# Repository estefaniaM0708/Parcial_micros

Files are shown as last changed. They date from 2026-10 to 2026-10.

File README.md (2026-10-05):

# 🪙 Sistema de Logística de Monedas Inteligentes — Grupo 5

**Segundo parcial · Microcontroladores · Universidad Militar Nueva Granada**

> **Elemento diferencial del grupo (5):** *Selector en cadena de vasos de moneda por visión computacional → control por ESP32 → aparcamiento por voz.*

---

## Contenido

1. [Resumen](#1-resumen)
2. [Alcance y decisiones de diseño](#2-alcance-y-decisiones-de-diseño)
3. [Arquitectura del sistema](#3-arquitectura-del-sistema)
4. [Requerimientos funcionales y no funcionales](#4-requerimientos-funcionales-y-no-funcionales)
5. [Diagramas de bloques por módulo](#5-diagramas-de-bloques-por-módulo)
6. [Selección y justificación de materiales](#6-selección-y-justificación-de-materiales)
7. [Diseño mecánico y CAD del carro](#7-diseño-mecánico-y-cad-del-carro)
8. [Diseño electrónico: pines y esquemas](#8-diseño-electrónico-pines-y-esquemas)
9. [Identificación visual de monedas](#9-identificación-visual-de-monedas)
10. [Firmware de las ESP32-S3](#10-firmware-de-las-esp32-s3)
11. [Aplicación Streamlit: dashboard y control por voz](#11-aplicación-streamlit-dashboard-y-control-por-voz)
12. [Simulación en PyBullet](#12-simulación-en-pybullet)
13. [Paso a paso para ejecutar](#13-paso-a-paso-para-ejecutar)
14. [Resultados de las pruebas](#14-resultados-de-las-pruebas)
15. [Qué hace falta (trabajo pendiente)](#15-qué-hace-falta-trabajo-pendiente)
16. [Estructura del repositorio](#16-estructura-del-repositorio)
17. [Evidencias](#17-evidencias)

---

## 1. Resumen

Se diseñó, simuló e implementó en firmware la parte del *Sistema de Logística de Monedas Inteligentes* que corresponde al grupo 5:

| Etapa | Qué hace | Dónde |
|---|---|---|
| **Identificación de monedas** | Una **cinta transportadora** lleva cada moneda bajo una cámara; un programa de **visión por computador** (OpenCV) la identifica por **diámetro y color** (dorado/plateado, centro y anillo). | `1_vision/` |
| **Selector en cadena de vasos** | Una **cadena con 6 vasos** (uno por denominación + rechazo) gira para poner bajo la caída el vaso correcto; la moneda cae en él. | `2_estacion_esp32/` |
| **Carro con ESP32-S3** | Carro diferencial que recibe el vaso lleno, sigue la pista y **esquiva tres obstáculos** hasta la meta. | `3_carro_esp32/`, `6_cad/` |
| **Aparcamiento por voz** | La orden hablada (*«estaciona el carro»*) se convierte en texto y el carro retrocede solo hasta la estación usando su **ultrasonido trasero**. | `4_app_streamlit/` |
| **Dashboard en tiempo real** | Streamlit muestra **cantidad, valor y peso** de las monedas, el estado de los vasos y del carro, comunicándose **por Wi-Fi** con las ESP32-S3. | `4_app_streamlit/` |
| **Simulación** | Todo el flujo funciona en **PyBullet**, usando el **mismo código de visión** que la cámara real. | `5_simulacion/` |

---

## 2. Alcance y decisiones de diseño

La arquitectura general del parcial tiene cinco bloques: **contador de monedas → transporte y embalaje → carro → pista con obstáculos → dashboard y chatbot**. Sobre esa base, el grupo tomó estas decisiones:

1. **Identificación por cinta transportadora y visión (en lugar del contador por ranuras).** Las monedas entran una a una a una banda negra. Una compuerta las detiene bajo la cámara, el PC las identifica y la ESP32 decide a qué vaso van. Esto permite saber la **denominación exacta**, y con ella el **valor** y el **peso** de cada moneda, que son las variables que pide el dashboard.
2. **Selector en cadena de vasos (elemento diferencial 5).** En lugar de un actuador por denominación, una sola caída alimenta una **cadena cerrada con 6 vasos**. La cadena gira por el camino más corto hasta dejar el vaso correcto bajo la caída. Con un solo motor paso a paso se clasifican las 5 denominaciones más el rechazo.
3. **Control por ESP32 y aparcamiento por voz.** El carro no se conduce con un joystick. Recibe **órdenes habladas** desde la app (*estacionar, cargar, meta, alto, adelante…*). El aparcamiento es **automático**: en reversa, con el HC-SR04 trasero y un pitido de sensor de parqueo, se detiene a 6 cm de la estación.
4. **Comunicación inalámbrica por Wi-Fi (HTTP).** Cada ESP32-S3 tiene un pequeño servidor web (`/estado`, `/moneda`, `/entregar`, `/cmd`). La app de Streamlit y el programa de visión le hablan por HTTP. Si no hay red, cada placa crea su propio punto de acceso.
5. **Simulación primero.** Todo se validó en PyBullet a **escala 4:1**. La cámara virtual genera imágenes que se clasifican con `vision_monedas.py`, el mismo archivo que se usa con la cámara real.

---

## 3. Arquitectura del sistema

```mermaid
flowchart LR
    subgraph EST["🏭 Estación (ESP32-S3 #1)"]
        T[Tolva] --> B[Banda transportadora<br/>28BYJ-48 + ULN2003]
        B --> C{Compuerta<br/>servo SG90}
        C -->|moneda detenida<br/>sensor IR| CAM[(Cámara USB)]
        C -->|liberada| CAD[Caída]
        CAD --> CH[Cadena de 6 vasos<br/>NEMA 17 + A4988]
        CH --> EMP[Empujador servo<br/>+ celda de carga HX711]
    end
    subgraph PC["💻 Computador"]
        CAM --> VIS["vision_monedas.py<br/>OpenCV: diámetro + color"]
        APP[App Streamlit<br/>dashboard + voz]
    end
    subgraph CAR["🚗 Carro (ESP32-S3 #2)"]
        MOT[2 motores TT<br/>TB6612FNG]
        US[HC-SR04 frontal y trasero]
        IR[3 sensores de línea TCRT5000]
    end
    VIS -- "HTTP /moneda?valor=500" --> EST
    APP -- "HTTP /estado · /entregar" --> EST
    APP -- "HTTP /cmd?c=estacionar" --> CAR
    EMP -- "vaso lleno" --> CAR
    CAR --> P[Pista con 3 obstáculos] --> M[🏁 Meta]
```

### Secuencia de operación

```mermaid
sequenceDiagram
    participant U as Usuario (voz)
    participant A as App Streamlit
    participant V as Visión (PC)
    participant E as ESP32 Estación
    participant C as ESP32 Carro
    E->>E: Banda avanza hasta que el IR detecta una moneda (compuerta cerrada)
    V->>V: Captura → segmenta → mide Ø y color → $500
    V->>E: GET /moneda?valor=500
    E->>E: Cadena gira al vaso de $500, abre compuerta, la moneda cae
    A->>E: GET /estado (cada 1 s) → dashboard
    U->>A: «estaciona el carro»
    A->>C: GET /cmd?c=estacionar
    C->>C: Reversa con ultrasonido trasero hasta 6 cm (pitidos)
    U->>A: «carga el vaso de quinientos»
    A->>E: GET /entregar?valor=500
    E->>E: Cadena lleva el vaso al puesto de entrega, lo pesa y lo empuja al carro
    U->>A: «ve a la meta»
    A->>C: GET /cmd?c=meta
    C->>C: Sigue la línea, esquiva 3 obstáculos, se detiene en la franja de meta
```

---

## 4. Requerimientos funcionales y no funcionales

### Funcionales

| ID | Requerimiento | Cómo se cumple |
|---|---|---|
| RF-01 | Identificar las monedas colombianas de $50, $100, $200, $500 y $1000 | Visión por diámetro (±0,6 mm) y color de centro y anillo |
| RF-02 | Separar cada moneda en el vaso de su denominación | Cadena de vasos indexada por motor paso a paso |
| RF-03 | Enviar a un vaso de rechazo las monedas no reconocidas | Puesto "rechazo" y *timeout* de 5 s sin respuesta de visión |
| RF-04 | Calcular cantidad, valor y peso de las monedas procesadas | Tabla de pesos oficiales + celda de carga en la entrega |
| RF-05 | Entregar un vaso lleno al carro | Empujador en el puesto de entrega + porta-vaso en el carro |
| RF-06 | Estacionar el carro en la zona de carga por orden de voz | Reconocimiento de voz en la app + reversa con HC-SR04 |
| RF-07 | Llevar el vaso a la meta esquivando 3 obstáculos | Seguidor de línea + ultrasonido frontal + maniobra de esquive |
| RF-08 | Mostrar las métricas en tiempo real | Dashboard Streamlit que consulta `/estado` cada 1 s |
| RF-09 | Comunicación inalámbrica PC ↔ ESP32 | Wi-Fi + HTTP (STA o punto de acceso propio) |

### No funcionales

| ID | Requerimiento | Valor objetivo |
|---|---|---|
| RNF-01 | Exactitud de clasificación | ≥ 95 % con iluminación controlada |
| RNF-02 | Tiempo por moneda | ≤ 8 s (inspección + indexado + caída) |
| RNF-03 | Latencia de las órdenes de voz | ≤ 2 s desde que se termina de hablar |
| RNF-04 | Precisión de aparcamiento | ± 1 cm de la distancia objetivo (6 cm) |
| RNF-05 | Autonomía del carro | ≥ 30 min con 2 × 18650 |
| RNF-06 | Seguridad | Parada ante obstáculo < 18 cm; comandos manuales temporizados |
| RNF-07 | Mantenibilidad | Pines, velocidades y umbrales agrupados como constantes al inicio de cada archivo |
| RNF-08 | Reproducibilidad | Toda la lógica probada en simulación antes del montaje |

---

## 5. Diagramas de bloques por módulo

### Estación (banda + selector en cadena)

```mermaid
flowchart TB
    F12[Fuente 12 V 3 A] --> A4988[Driver A4988] --> N17[NEMA 17: cadena de vasos]
    F12 --> BUCK1[LM2596 → 5 V] --> ULN[ULN2003] --> M28[28BYJ-48: banda]
    BUCK1 --> SV1[Servo compuerta]
    BUCK1 --> SV2[Servo empujador]
    BUCK1 --> ESP1[ESP32-S3 #1]
    IRM[Sensor IR FC-51<br/>moneda en inspección] --> ESP1
    HOME[TCRT5000<br/>home de la cadena] --> ESP1
    CELDA[Celda de carga 1 kg] --> HX[HX711] --> ESP1
    ESP1 --> A4988
    ESP1 --> ULN
    ESP1 --> SV1
    ESP1 --> SV2
    ESP1 <-. Wi-Fi .-> PC[("PC: visión + app")]
```

### Visión por computador

```mermaid
flowchart LR
    CAM[Cámara USB cenital<br/>+ anillo LED] --> HSV[BGR → HSV]
    HSV --> UMB["Umbral de brillo V &gt; 80<br/>banda negra"]
    UMB --> MOR[Apertura + cierre]
    MOR --> CON[Contornos<br/>área y circularidad]
    CON --> DIA[Diámetro equivalente<br/>px → mm]
    CON --> COL[Color del centro y del anillo<br/>H y S en HSV]
    DIA --> CLA[Costo mínimo<br/>vs tabla de monedas]
    COL --> CLA
    CLA --> HTTP[HTTP a la estación]
```

### Carro

```mermaid
flowchart TB
    BAT[2 × 18650 · 7,4 V] --> SW[Interruptor] --> TB[TB6612FNG]
    SW --> BUCK[MP1584 → 5 V] --> ESP2[ESP32-S3 #2]
    BUCK --> USF[HC-SR04 frontal]
    BUCK --> UST[HC-SR04 trasero]
    TB --> MI[Motor TT izquierdo]
    TB --> MD[Motor TT derecho]
    LIN[3 × TCRT5000] --> ESP2
    USF --> ESP2
    UST --> ESP2
    ESP2 --> TB
    ESP2 --> BZ[Buzzer de parqueo]
    ESP2 <-. Wi-Fi .-> APP[(App Streamlit)]
```

---

## 6. Selección y justificación de materiales

| Componente | Cant. | Selección | Justificación |
|---|---|---|---|
| Microcontrolador | 2 | **ESP32-S3 DevKitC-1** | Wi-Fi integrado para el dashboard, doble núcleo, MicroPython, muchos GPIO y ADC; el curso ya lo usa |
| Banda transportadora | 1 | 28BYJ-48 + ULN2003, banda de caucho/EVA **negra** de 40 mm | Velocidad baja y constante (~19 mm/s), barato; el negro da contraste a la visión |
| Cadena de vasos | 1 | **NEMA 17 + A4988** (1/8 de micropaso), piñón Ø40 mm, cadena/correa cerrada | Par y velocidad suficientes para mover 6 vasos con monedas (~1 s por puesto); posicionamiento en lazo abierto preciso |
| Compuerta y empujador | 2 | Servo **SG90 / MG90S** | Movimiento angular simple, control directo por PWM |
| Detección de moneda | 1 | Sensor IR **FC-51** | Detecta la moneda bajo la cámara para detener la banda |
| Referencia de la cadena | 1 | **TCRT5000** | *Homing* del puesto 0 al encender |
| Peso | 1 | Celda de carga 1 kg + **HX711** | Mide el peso real del vaso antes de entregarlo (variable "peso" del dashboard) |
| Cámara | 1 | Webcam USB 1080p + anillo LED | Resolución de ~10 px/mm a 12 cm; luz uniforme para medir el color |
| Motores del carro | 2 | **Motorreductor TT 1:48** + rueda 65 mm | Estándar, económico y con el par suficiente para 0,9 kg |
| Driver del carro | 1 | **TB6612FNG** | Lógica de 3,3 V y mayor eficiencia que el L298N (menor caída de tensión) |
| Distancia | 2 | **HC-SR04** (frontal y trasero) | El trasero hace el aparcamiento; el frontal detecta los obstáculos (ECHO con divisor a 3,3 V) |
| Línea | 3 | **TCRT5000** | Seguir la línea de la pista y detectar la franja de meta |
| Energía del carro | 1 | 2 × 18650 + **MP1584** 5 V | 7,4 V para los motores y 5 V regulados para la lógica |
| Estructura del carro | — | PLA impreso / acrílico 4 mm | Piezas del CAD de este repositorio; fáciles de fabricar |
| Vasos | 6 | Vasos de Ø70 mm | Encajan en el porta-vaso de Ø78 mm del carro |

---

## 7. Diseño mecánico y CAD del carro

El CAD está en `6_cad/` y se genera desde **una sola fuente de cotas** (`generar_cad.py`):

| Archivo | Uso |
|---|---|
| `carro.scad` | Modelo **paramétrico** para OpenSCAD (gratuito). Con la variable `pieza` se exporta cada parte imprimible: `chasis`, `piso2`, `portavaso`, `soporte_sensor` (F6 → F7 = STL) |
| `carro_ensamble.stl` | Ensamble 3D completo en mm (se abre en cualquier visor o *slicer*) |
| `carro.urdf` | Modelo para PyBullet (escala 4:1, la de la simulación) |
| `plano_carro.png` | Plano con vistas superior y lateral acotadas |

| Isométrica | Trasera (porta-vaso) |
|---|---|
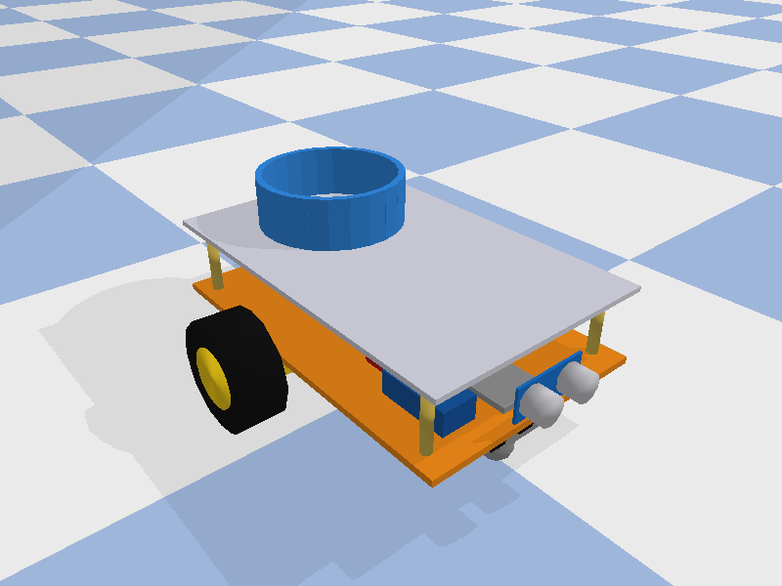
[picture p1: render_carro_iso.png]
CAD isométrico
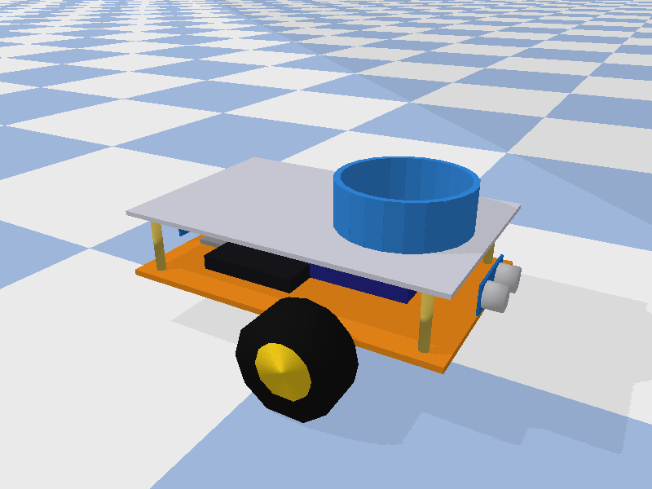
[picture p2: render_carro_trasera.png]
CAD trasera
|  |  |

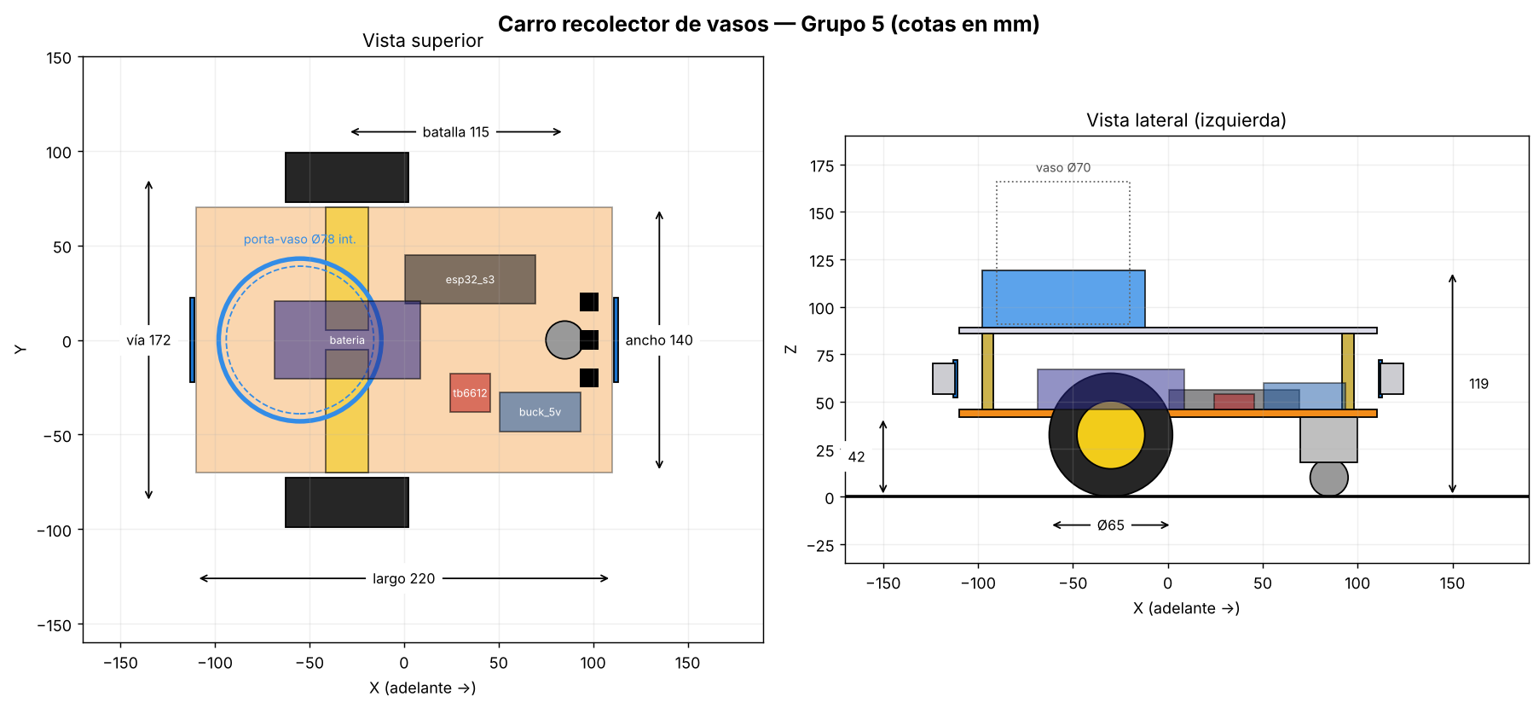
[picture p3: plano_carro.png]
Plano acotado


### Cotas principales

| Parámetro | Valor |
|---|---|
| Chasis (largo × ancho) | 220 × 140 mm, dos pisos (4 mm + 3 mm) con separadores de 40 mm |
| Ruedas motrices | Ø65 mm, vía 172 mm, eje a 30 mm detrás del centro |
| Rueda loca | Bola de Ø20 mm, a 85 mm delante del centro (batalla 115 mm) |
| Porta-vaso | Ø78 mm interior × 30 mm de alto, sobre el piso superior (atrás) |
| Altura total | 119 mm (sin vaso) |
| Sensores | HC-SR04 adelante y atrás; 3 × TCRT5000 bajo la parte delantera |

**Por qué el porta-vaso va atrás:** el carro se **estaciona en reversa**, así que el porta-vaso queda pegado al empujador de la estación, y el sensor trasero mide justo esa distancia.

### Estación

| Elemento | Dimensiones reales |
|---|---|
| Banda | 400 × 40 mm, superficie negra, rodillos Ø25 mm con rodamientos 608 |
| Cámara | A 105 mm sobre la banda, en la zona de inspección (a 75 mm del final) |
| Cadena de vasos | Óvalo de 1170 mm (6 puestos cada 195 mm), piñones Ø40 mm |
| Puestos | Caída en el puesto 0; entrega en el puesto 3 (lado opuesto) |

<details>
<summary><b>Código: <code>6_cad/generar_cad.py</code></b> (genera SCAD, STL, URDF y plano)</summary>

```python
"""
generar_cad.py  -  CAD del carro recolector de vasos (Grupo 5)

Una sola fuente de verdad para el diseño mecánico del carro. A partir de las
cotas reales (en mm) este script genera:

  carro.scad           modelo paramétrico para OpenSCAD (editable; F6 + F7 exporta STL)
  carro_ensamble.stl   ensamble 3D en mm (para ver en cualquier visor/slicer)
  carro.urdf           modelo para PyBullet (escala configurable)
  plano_carro.png      plano con vistas superior y lateral acotadas

Uso:  python generar_cad.py            (escala del URDF = 4, la de la simulación)
      python generar_cad.py --escala 1 (URDF a tamaño real)
"""

import argparse
import math
import os
import struct

AQUI = os.path.dirname(os.path.abspath(__file__))

# ---------------------------------------------------------------------------
# COTAS DEL CARRO (mm). Ejes: X adelante, Y izquierda, Z arriba. Origen: centro
# del chasis inferior a nivel del piso.
# ---------------------------------------------------------------------------
L, W = 220.0, 140.0            # chasis inferior (acrilico / PLA 4 mm)
T_CHASIS = 4.0
Z_CHASIS = 42.0                # cara inferior del chasis
R_RUEDA, A_RUEDA = 32.5, 26.0  # rueda TT de 65 mm
X_EJE = -30.0                  # eje de las ruedas motrices
Y_RUEDA = W / 2 + 3 + A_RUEDA / 2
MOTOR = (65.0, 22.5, 18.8)     # motorreductor TT (largo en Y)
X_LOCA, R_BOLA = 85.0, 10.0    # rueda loca (ball caster)
H_SEPARADOR, R_SEPARADOR = 40.0, 3.0
T_PISO2 = 3.0                  # chasis superior
Z_PISO2 = Z_CHASIS + T_CHASIS + H_SEPARADOR
X_VASO = -55.0                 # porta-vaso sobre el piso superior
R_EXT_VASO, R_INT_VASO, H_PORTAVASO = 43.0, 39.0, 30.0

# Componentes (centro x, centro y, tamaño x, tamaño y, tamaño z, z inferior, color)
Z_SUP = Z_CHASIS + T_CHASIS
COMPONENTES = {
    "esp32_s3":  (35.0, 32.0, 69.0, 26.0, 10.0, Z_SUP, (0.10, 0.10, 0.12)),
    "tb6612":    (35.0, -28.0, 21.0, 20.0, 8.0, Z_SUP, (0.75, 0.10, 0.10)),
    "bateria":   (-30.0, 0.0, 77.0, 41.0, 21.0, Z_SUP, (0.15, 0.15, 0.55)),
    "buck_5v":   (72.0, -38.0, 43.0, 21.0, 14.0, Z_SUP, (0.10, 0.35, 0.65)),
}
HCSR04 = [(+1, L / 2 + 2.0), (-1, -L / 2 - 2.0)]   # (sentido, x de la placa)
Z_HCSR04 = Z_SUP + 16.0
IR_LINEA = [(L / 2 - 12.0, y) for y in (-20.0, 0.0, 20.0)]

COLORES = {
    "chasis": (0.95, 0.55, 0.10), "piso2": (0.85, 0.85, 0.90), "rueda": (0.08, 0.08, 0.08),
    "rin": (0.95, 0.80, 0.10), "motor": (0.95, 0.80, 0.10), "loca": (0.6, 0.6, 0.6),
    "separador": (0.80, 0.70, 0.30), "portavaso": (0.20, 0.55, 0.90), "sensor": (0.10, 0.45, 0.80),
    "transductor": (0.80, 0.80, 0.82), "ir": (0.05, 0.05, 0.05),
}

# ---------------------------------------------------------------------------
# Lista de piezas como primitivas (sirve para STL, URDF y plano)
# ---------------------------------------------------------------------------
def piezas():
    """Devuelve (nombre, tipo, parametros, color). Tipos: caja / cilindro / esfera.
    caja: (cx, cy, cz, sx, sy, sz); cilindro: (cx, cy, cz, r, h, eje); esfera: (cx, cy, cz, r)"""
    p = []
    p.append(("chasis", "caja", (0, 0, Z_CHASIS + T_CHASIS / 2, L, W, T_CHASIS), COLORES["chasis"]))
    p.append(("piso2", "caja", (0, 0, Z_PISO2 + T_PISO2 / 2, L, W, T_PISO2), COLORES["piso2"]))
    for sx in (-1, 1):
        for sy in (-1, 1):
            p.append(("separador", "cilindro",
                      (sx * (L / 2 - 15), sy * (W / 2 - 10), Z_SUP + H_SEPARADOR / 2,
                       R_SEPARADOR, H_SEPARADOR, "z"), COLORES["separador"]))
    for s in (-1, 1):
        p.append(("motor", "caja", (X_EJE, s * (5 + MOTOR[0] / 2), Z_CHASIS - MOTOR[2] / 2,
                                    MOTOR[1], MOTOR[0], MOTOR[2]), COLORES["motor"]))
        p.append(("rueda", "cilindro", (X_EJE, s * Y_RUEDA, R_RUEDA, R_RUEDA, A_RUEDA, "y"), COLORES["rueda"]))
        p.append(("rin", "cilindro", (X_EJE, s * (Y_RUEDA + A_RUEDA / 2), R_RUEDA,
                                      R_RUEDA * 0.55, 2.0, "y"), COLORES["rin"]))
    p.append(("soporte_loca", "caja", (X_LOCA, 0, (2 * R_BOLA + Z_CHASIS) / 2 + R_BOLA / 2,
                                       30, 30, Z_CHASIS - 1.5 * R_BOLA), COLORES["loca"]))
    p.append(("bola_loca", "esfera", (X_LOCA, 0, R_BOLA, R_BOLA), COLORES["loca"]))
    for nombre, (cx, cy, sx, sy, sz, z0, color) in COMPONENTES.items():
        p.append((nombre, "caja", (cx, cy, z0 + sz / 2, sx, sy, sz), color))
    for sentido, x in HCSR04:
        p.append(("hcsr04", "caja", (x, 0, Z_HCSR04, 1.6, 45.0, 20.0), COLORES["sensor"]))
        for y in (-13.0, 13.0):
            p.append(("transductor", "cilindro", (x + sentido * 6.8, y, Z_HCSR04, 8.0, 12.0, "x"),
                      COLORES["transductor"]))
    for x, y in IR_LINEA:
        p.append(("ir_linea", "caja", (x, y, Z_CHASIS - 6, 10, 10, 12), COLORES["ir"]))
    # porta-vaso: anillo formado por 24 segmentos (para STL/URDF) / tubo en OpenSCAD
    n = 24
    r_med = (R_EXT_VASO + R_INT_VASO) / 2
    ancho = 2 * math.pi * r_med / n * 1.05
    for i in range(n):
        a = 2 * math.pi * i / n
        p.append(("portavaso", "caja_rot",
                  (X_VASO + r_med * math.cos(a), r_med * math.sin(a), Z_PISO2 + T_PISO2 + H_PORTAVASO / 2,
                   R_EXT_VASO - R_INT_VASO, ancho, H_PORTAVASO, a), COLORES["portavaso"]))
    return p

# ---------------------------------------------------------------------------
# 1) OpenSCAD
# ---------------------------------------------------------------------------
def generar_scad(ruta):
    s = f"""// carro.scad - Carro recolector de vasos (Grupo 5) - cotas en mm
// Generado por generar_cad.py. Abrir en OpenSCAD: F5 vista previa, F6 render, F7 exportar STL.
// Cambia "pieza" para exportar cada parte imprimible por separado.

pieza = "ensamble";   // "ensamble", "chasis", "piso2", "portavaso", "soporte_sensor"
$fn = 64;

L = {L}; W = {W};
t_chasis = {T_CHASIS}; z_chasis = {Z_CHASIS};
r_rueda = {R_RUEDA}; a_rueda = {A_RUEDA};
x_eje = {X_EJE}; y_rueda = {Y_RUEDA};
x_loca = {X_LOCA}; r_bola = {R_BOLA};
h_sep = {H_SEPARADOR}; t_piso2 = {T_PISO2};
z_piso2 = z_chasis + t_chasis + h_sep;
x_vaso = {X_VASO}; r_ext_vaso = {R_EXT_VASO}; r_int_vaso = {R_INT_VASO}; h_portavaso = {H_PORTAVASO};
r_esquina = 10;

module placa_redondeada(l, w, t, r) {{
    hull() for (sx = [-1, 1], sy = [-1, 1])
        translate([sx * (l / 2 - r), sy * (w / 2 - r), 0]) cylinder(r = r, h = t);
}}

// Chasis inferior: agujeros para separadores, rueda loca, motores y paso de cables
module chasis() {{
    difference() {{
        placa_redondeada(L, W, t_chasis, r_esquina);
        for (sx = [-1, 1], sy = [-1, 1])
            translate([sx * (L / 2 - 15), sy * (W / 2 - 10), -1]) cylinder(d = 3.4, h = t_chasis + 2);
        for (dx = [-10, 10], dy = [-10, 10])                 // rueda loca
            translate([x_loca + dx, dy, -1]) cylinder(d = 3.4, h = t_chasis + 2);
        for (s = [-1, 1], dx = [-8, 8])                      // soportes de motor
            translate([x_eje + dx, s * 40, -1]) cylinder(d = 3.4, h = t_chasis + 2);
        translate([0, 0, -1]) linear_extrude(t_chasis + 2)   // paso de cables
            hull() {{ translate([-10, 0]) circle(d = 14); translate([10, 0]) circle(d = 14); }}
        for (y = [-20, 0, 20])                                // sensores IR de linea
            translate([L / 2 - 12, y, -1]) cylinder(d = 3.4, h = t_chasis + 2);
    }}
}}

// Chasis superior con agujero para el porta-vaso y ventilacion
module piso2() {{
    difference() {{
        placa_redondeada(L, W, t_piso2, r_esquina);
        for (sx = [-1, 1], sy = [-1, 1])
            translate([sx * (L / 2 - 15), sy * (W / 2 - 10), -1]) cylinder(d = 3.4, h = t_piso2 + 2);
        for (i = [0 : 3])
            translate([20 + i * 18, -25, -1]) cube([10, 50, t_piso2 + 2]);
    }}
}}

// Porta-vaso: tubo con base, recibe un vaso de 70 mm
module portavaso() {{
    difference() {{
        union() {{
            cylinder(r = r_ext_vaso, h = h_portavaso);
            cylinder(r = r_ext_vaso + 6, h = 2);             // pestaña de apoyo
        }}
        translate([0, 0, 2]) cylinder(r = r_int_vaso, h = h_portavaso);
        translate([0, 0, -1]) cylinder(r = r_int_vaso - 8, h = 4);
        translate([-r_ext_vaso - 1, -8, 12]) cube([10, 16, h_portavaso]);   // ranura sensor
    }}
}}

// Soporte en L para el HC-SR04
module soporte_sensor() {{
    difference() {{
        union() {{
            translate([-2, -25, 0]) cube([2, 50, 26]);
            translate([-14, -25, 0]) cube([14, 50, 2]);
        }}
        for (y = [-13, 13]) translate([-3, y, 16]) rotate([0, 90, 0]) cylinder(d = 16.5, h = 4);
        for (y = [-18, 18]) translate([-7, y, -1]) cylinder(d = 3.4, h = 4);
    }}
}}

module rueda() {{ rotate([90, 0, 0]) cylinder(r = r_rueda, h = a_rueda, center = true); }}
module motor_tt() {{ cube([22.5, 65, 18.8], center = true); }}

module ensamble() {{
    color("orange") translate([0, 0, z_chasis]) chasis();
    color("gainsboro") translate([0, 0, z_piso2]) piso2();
    color("goldenrod") for (sx = [-1, 1], sy = [-1, 1])
        translate([sx * (L / 2 - 15), sy * (W / 2 - 10), z_chasis + t_chasis]) cylinder(r = 3, h = h_sep);
    for (s = [-1, 1]) {{
        color("gold") translate([x_eje, s * (5 + 65 / 2), z_chasis - 18.8 / 2]) motor_tt();
        color("black") translate([x_eje, s * y_rueda, r_rueda]) rueda();
    }}
    color("silver") translate([x_loca, 0, r_bola]) sphere(r = r_bola);
    color("silver") translate([x_loca - 15, -15, 2 * r_bola - 2]) cube([30, 30, z_chasis - 2 * r_bola + 2]);
    color("dodgerblue") translate([x_vaso, 0, z_piso2 + t_piso2]) portavaso();
    color("steelblue") translate([L / 2, 0, z_chasis + t_chasis]) soporte_sensor();
    color("steelblue") translate([-L / 2, 0, z_chasis + t_chasis]) mirror([1, 0, 0]) soporte_sensor();
"""
    for nombre, (cx, cy, sx, sy, sz, z0, color) in COMPONENTES.items():
        s += (f"    color([{color[0]}, {color[1]}, {color[2]}]) "
              f"translate([{cx - sx / 2}, {cy - sy / 2}, {z0}]) cube([{sx}, {sy}, {sz}]);  // {nombre}\n")
    s += """}

if (pieza == "ensamble") ensamble();
if (pieza == "chasis") chasis();
if (pieza == "piso2") piso2();
if (pieza == "portavaso") portavaso();
if (pieza == "soporte_sensor") soporte_sensor();
"""
    with open(ruta, "w", encoding="utf-8") as f:
        f.write(s)

# ---------------------------------------------------------------------------
# 2) STL (ensamble de primitivas)
# ---------------------------------------------------------------------------
def _caja(c, s, ang=0.0):
    cx, cy, cz = c
    hx, hy, hz = s[0] / 2, s[1] / 2, s[2] / 2
    ca, sa = math.cos(ang), math.sin(ang)
    v = []
    for dx, dy, dz in [(-1, -1, -1), (1, -1, -1), (1, 1, -1), (-1, 1, -1),
                       (-1, -1, 1), (1, -1, 1), (1, 1, 1), (-1, 1, 1)]:
        x, y = dx * hx, dy * hy
        v.append((cx + ca * x - sa * y, cy + sa * x + ca * y, cz + dz * hz))
    caras = [(0, 2, 1), (0, 3, 2), (4, 5, 6), (4, 6, 7), (0, 1, 5), (0, 5, 4),
             (1, 2, 6), (1, 6, 5), (2, 3, 7), (2, 7, 6), (3, 0, 4), (3, 4, 7)]
    return [(v[a], v[b], v[c]) for a, b, c in caras]

def _cilindro(c, r, h, eje, n=40):
    def punto(a, t):
        u, w = r * math.cos(a), r * math.sin(a)
        if eje == "z":
            return (c[0] + u, c[1] + w, c[2] + t)
        if eje == "y":
            return (c[0] + u, c[1] + t, c[2] + w)
        return (c[0] + t, c[1] + u, c[2] + w)
    tri = []
    for i in range(n):
        a0, a1 = 2 * math.pi * i / n, 2 * math.pi * (i + 1) / n
        p0, p1 = punto(a0, -h / 2), punto(a1, -h / 2)
        q0, q1 = punto(a0, h / 2), punto(a1, h / 2)
        cb = {"z": (c[0], c[1], c[2] - h / 2), "y": (c[0], c[1] - h / 2, c[2]), "x": (c[0] - h / 2, c[1], c[2])}[eje]
        ct = {"z": (c[0], c[1], c[2] + h / 2), "y": (c[0], c[1] + h / 2, c[2]), "x": (c[0] + h / 2, c[1], c[2])}[eje]
        tri += [(p0, p1, q1), (p0, q1, q0), (cb, p1, p0), (ct, q0, q1)]
    if eje == "y":   # el eje y invierte la orientacion de las caras
        tri = [(a, c_, b) for a, b, c_ in tri]
    return tri

def _esfera(c, r, n=20):
    tri = []
    for i in range(n):
        t0, t1 = math.pi * i / n, math.pi * (i + 1) / n
        for j in range(2 * n):
            f0, f1 = 2 * math.pi * j / (2 * n), 2 * math.pi * (j + 1) / (2 * n)
            def pt(t, f):
                return (c[0] + r * math.sin(t) * math.cos(f), c[1] + r * math.sin(t) * math.sin(f), c[2] + r * math.cos(t))
            a, b, cc, d = pt(t0, f0), pt(t1, f0), pt(t1, f1), pt(t0, f1)
            tri += [(a, b, cc), (a, cc, d)]
    return tri

def triangulos():
    tri = []
    for nombre, tipo, prm, _ in piezas():
        if tipo == "caja":
            tri += _caja(prm[:3], prm[3:6])
        elif tipo == "caja_rot":
            tri += _caja(prm[:3], prm[3:6], prm[6])
        elif tipo == "cilindro":
            tri += _cilindro(prm[:3], prm[3], prm[4], prm[5])
        else:
            tri += _esfera(prm[:3], prm[3])
    return tri

def generar_stl(ruta):
    tri = triangulos()
    with open(ruta, "wb") as f:
        f.write(b"carro recolector grupo 5 (mm)".ljust(80, b" "))
        f.write(struct.pack("<I", len(tri)))
        for a, b, c in tri:
            u = [b[i] - a[i] for i in range(3)]
            v = [c[i] - a[i] for i in range(3)]
            n = (u[1] * v[2] - u[2] * v[1], u[2] * v[0] - u[0] * v[2], u[0] * v[1] - u[1] * v[0])
            m = math.sqrt(sum(x * x for x in n)) or 1.0
            f.write(struct.pack("<12fH", n[0] / m, n[1] / m, n[2] / m, *a, *b, *c, 0))
    return len(tri)

# ---------------------------------------------------------------------------
# 3) URDF para PyBullet
# ---------------------------------------------------------------------------
def generar_urdf(ruta, escala):
    k = escala / 1000.0                     # mm -> m, multiplicado por la escala
    z_base = Z_CHASIS + T_CHASIS / 2        # el marco del chasis esta en su centro

    def f(v):
        return " ".join("%.5f" % x for x in v)

    visuales = []
    for nombre, tipo, prm, color in piezas():
        if nombre in ("rueda", "rin", "bola_loca"):
            continue
        mat = '<material name="m_%s"><color rgba="%.2f %.2f %.2f 1"/></material>' % (nombre, *color)
        if tipo in ("caja", "caja_rot"):
            cx, cy, cz, sx, sy, sz = prm[:6]
            yaw = prm[6] if tipo == "caja_rot" else 0.0
            visuales.append(
                f'    <visual name="{nombre}"><origin xyz="{f((cx * k, cy * k, (cz - z_base) * k))}" rpy="0 0 {yaw:.5f}"/>'
                f'<geometry><box size="{f((sx * k, sy * k, sz * k))}"/></geometry>{mat}</visual>')
        elif tipo == "cilindro":
            cx, cy, cz, r, h, eje = prm
            rpy = {"z": "0 0 0", "y": "1.5708 0 0", "x": "0 1.5708 0"}[eje]
            visuales.append(
                f'    <visual name="{nombre}"><origin xyz="{f((cx * k, cy * k, (cz - z_base) * k))}" rpy="{rpy}"/>'
                f'<geometry><cylinder radius="{r * k:.5f}" length="{h * k:.5f}"/></geometry>{mat}</visual>')

    masa_chasis = 0.9 * escala                     # kg (0,9 kg reales; se escala para la simulacion)
    Lm, Wm, Hm = L * k, W * k, (Z_PISO2 + T_PISO2 - Z_CHASIS) * k
    Ixx = masa_chasis * (Wm ** 2 + Hm ** 2) / 12
    Iyy = masa_chasis * (Lm ** 2 + Hm ** 2) / 12
    Izz = masa_chasis * (Lm ** 2 + Wm ** 2) / 12
    m_rueda = 0.05 * escala
    Ir_eje = m_rueda * (R_RUEDA * k) ** 2 / 2
    Ir_rad = m_rueda * (3 * (R_RUEDA * k) ** 2 + (A_RUEDA * k) ** 2) / 12
    colisiones = (
        f'    <collision><origin xyz="0 0 0"/><geometry><box size="{f((L * k, W * k, T_CHASIS * k))}"/></geometry></collision>\n'
        f'    <collision><origin xyz="0 0 {(Z_PISO2 + T_PISO2 / 2 - z_base) * k:.5f}"/>'
        f'<geometry><box size="{f((L * k, W * k, T_PISO2 * k))}"/></geometry></collision>\n'
        f'    <collision><origin xyz="{f((-30 * k, 0, (Z_SUP + 10 - z_base) * k))}"/>'
        f'<geometry><box size="{f((90 * k, 50 * k, 20 * k))}"/></geometry></collision>')

    rueda = lambda lado, s: f"""
  <link name="rueda_{lado}">
    <visual><origin rpy="1.5708 0 0"/><geometry><cylinder radius="{R_RUEDA * k:.5f}" length="{A_RUEDA * k:.5f}"/></geometry>
      <material name="m_rueda"><color rgba="0.08 0.08 0.08 1"/></material></visual>
    <visual><origin xyz="0 {s * A_RUEDA / 2 * k:.5f} 0" rpy="1.5708 0 0"/><geometry><cylinder radius="{R_RUEDA * 0.55 * k:.5f}" length="{2 * k:.5f}"/></geometry>
      <material name="m_rin"><color rgba="0.95 0.8 0.1 1"/></material></visual>
    <collision><origin rpy="1.5708 0 0"/><geometry><cylinder radius="{R_RUEDA * k:.5f}" length="{A_RUEDA * k:.5f}"/></geometry></collision>
    <inertial><mass value="{m_rueda:.3f}"/><inertia ixx="{Ir_rad:.6f}" iyy="{Ir_eje:.6f}" izz="{Ir_rad:.6f}" ixy="0" ixz="0" iyz="0"/></inertial>
  </link>
  <joint name="motor_{lado}" type="continuous">
    <parent link="chasis"/><child link="rueda_{lado}"/>
    <origin xyz="{f((X_EJE * k, s * Y_RUEDA * k, (R_RUEDA - z_base) * k))}"/><axis xyz="0 1 0"/>
  </joint>"""

    urdf = f"""<?xml version="1.0"?>
<!-- carro.urdf - Carro recolector de vasos (Grupo 5). Generado por generar_cad.py, escala {escala}:1 -->
<robot name="carro_recolector">
  <link name="chasis">
{chr(10).join(visuales)}
{colisiones}
    <inertial><origin xyz="{-15 * k:.5f} 0 0"/><mass value="{masa_chasis:.3f}"/>
      <inertia ixx="{Ixx:.6f}" iyy="{Iyy:.6f}" izz="{Izz:.6f}" ixy="0" ixz="0" iyz="0"/></inertial>
  </link>
{rueda("izq", 1)}
{rueda("der", -1)}
  <link name="rueda_loca">
    <visual><geometry><sphere radius="{R_BOLA * k:.5f}"/></geometry>
      <material name="m_loca"><color rgba="0.6 0.6 0.6 1"/></material></visual>
    <collision><geometry><sphere radius="{R_BOLA * k:.5f}"/></geometry></collision>
    <inertial><mass value="{0.01 * escala:.3f}"/><inertia ixx="{Ir_rad / 5:.6f}" iyy="{Ir_rad / 5:.6f}" izz="{Ir_rad / 5:.6f}" ixy="0" ixz="0" iyz="0"/></inertial>
  </link>
  <joint name="loca" type="fixed">
    <parent link="chasis"/><child link="rueda_loca"/>
    <origin xyz="{f((X_LOCA * k, 0, (R_BOLA - z_base) * k))}"/>
  </joint>
  <link name="porta_vaso"><inertial><mass value="0.001"/><inertia ixx="1e-6" iyy="1e-6" izz="1e-6" ixy="0" ixz="0" iyz="0"/></inertial></link>
  <joint name="porta_vaso" type="fixed">
    <parent link="chasis"/><child link="porta_vaso"/>
    <origin xyz="{f((X_VASO * k, 0, (Z_PISO2 + T_PISO2 - z_base) * k))}"/>
  </joint>
  <link name="sensor_frontal"><inertial><mass value="0.001"/><inertia ixx="1e-6" iyy="1e-6" izz="1e-6" ixy="0" ixz="0" iyz="0"/></inertial></link>
  <joint name="sensor_frontal" type="fixed">
    <parent link="chasis"/><child link="sensor_frontal"/>
    <origin xyz="{f(((L / 2 + 14) * k, 0, (Z_HCSR04 - z_base) * k))}"/>
  </joint>
  <link name="sensor_trasero"><inertial><mass value="0.001"/><inertia ixx="1e-6" iyy="1e-6" izz="1e-6" ixy="0" ixz="0" iyz="0"/></inertial></link>
  <joint name="sensor_trasero" type="fixed">
    <parent link="chasis"/><child link="sensor_trasero"/>
    <origin xyz="{f((-(L / 2 + 14) * k, 0, (Z_HCSR04 - z_base) * k))}" rpy="0 0 3.14159"/>
  </joint>
</robot>
"""
    with open(ruta, "w", encoding="utf-8") as fh:
        fh.write(urdf)

# ---------------------------------------------------------------------------
# 4) Plano acotado
# ---------------------------------------------------------------------------
def generar_plano(ruta):
    import matplotlib
    matplotlib.use("Agg")
    import matplotlib.pyplot as plt
    from matplotlib.patches import Rectangle, Circle

    fig, (a1, a2) = plt.subplots(1, 2, figsize=(14, 6.2))
    fig.suptitle("Carro recolector de vasos — Grupo 5 (cotas en mm)", fontsize=14, weight="bold")

    def cota(ax, p0, p1, texto, off=(0, 0)):
        ax.annotate("", p0, p1, arrowprops=dict(arrowstyle="<->", lw=1))
        ax.text((p0[0] + p1[0]) / 2 + off[0], (p0[1] + p1[1]) / 2 + off[1], texto,
                ha="center", va="center", fontsize=9, backgroundcolor="white")

    # --- vista superior ---
    a1.set_title("Vista superior")
    a1.add_patch(Rectangle((-L / 2, -W / 2), L, W, fc=COLORES["chasis"], ec="k", alpha=0.35))
    for s in (-1, 1):
        a1.add_patch(Rectangle((X_EJE - R_RUEDA, s * Y_RUEDA - A_RUEDA / 2), 2 * R_RUEDA, A_RUEDA, fc="0.15", ec="k"))
        a1.add_patch(Rectangle((X_EJE - MOTOR[1] / 2, s * (5 + MOTOR[0] / 2) - MOTOR[0] / 2),
                               MOTOR[1], MOTOR[0], fc=COLORES["motor"], ec="k", alpha=0.6))
    a1.add_patch(Circle((X_LOCA, 0), R_BOLA, fc="0.6", ec="k"))
    a1.add_patch(Circle((X_VASO, 0), R_EXT_VASO, fc="none", ec=COLORES["portavaso"], lw=3))
    a1.add_patch(Circle((X_VASO, 0), R_INT_VASO, fc="none", ec=COLORES["portavaso"], lw=1, ls="--"))
    for nombre, (cx, cy, sx, sy, sz, z0, color) in COMPONENTES.items():
        a1.add_patch(Rectangle((cx - sx / 2, cy - sy / 2), sx, sy, fc=color, ec="k", alpha=0.55))
        a1.text(cx, cy, nombre, ha="center", va="center", fontsize=7, color="w")
    for _, x in HCSR04:
        a1.add_patch(Rectangle((x - 1, -22.5), 2, 45, fc=COLORES["sensor"], ec="k"))
    for x, y in IR_LINEA:
        a1.add_patch(Rectangle((x - 5, y - 5), 10, 10, fc="k"))
    cota(a1, (-L / 2, -Y_RUEDA - 40), (L / 2, -Y_RUEDA - 40), f"largo {L:.0f}")
    cota(a1, (L / 2 + 25, -W / 2), (L / 2 + 25, W / 2), f"ancho {W:.0f}", off=(0, 0))
    cota(a1, (-L / 2 - 25, Y_RUEDA), (-L / 2 - 25, -Y_RUEDA), f"vía {2 * Y_RUEDA:.0f}", off=(0, 0))
    cota(a1, (X_EJE, W / 2 + 40), (X_LOCA, W / 2 + 40), f"batalla {X_LOCA - X_EJE:.0f}")
    a1.text(X_VASO, R_EXT_VASO + 8, f"porta-vaso Ø{2 * R_INT_VASO:.0f} int.", ha="center", fontsize=8,
            color=COLORES["portavaso"])
    a1.set_xlim(-170, 190); a1.set_ylim(-160, 150); a1.set_aspect("equal"); a1.grid(alpha=0.2)
    a1.set_xlabel("X (adelante →)"); a1.set_ylabel("Y")

    # --- vista lateral ---
    a2.set_title("Vista lateral (izquierda)")
    a2.add_patch(Rectangle((-L / 2, Z_CHASIS), L, T_CHASIS, fc=COLORES["chasis"], ec="k"))
    a2.add_patch(Rectangle((-L / 2, Z_PISO2), L, T_PISO2, fc=COLORES["piso2"], ec="k"))
    for sx in (-1, 1):
        a2.add_patch(Rectangle((sx * (L / 2 - 15) - 3, Z_SUP), 6, H_SEPARADOR, fc=COLORES["separador"], ec="k"))
    a2.add_patch(Circle((X_EJE, R_RUEDA), R_RUEDA, fc="0.15", ec="k"))
    a2.add_patch(Circle((X_EJE, R_RUEDA), R_RUEDA * 0.55, fc=COLORES["rin"], ec="k"))
    a2.add_patch(Circle((X_LOCA, R_BOLA), R_BOLA, fc="0.6", ec="k"))
    a2.add_patch(Rectangle((X_LOCA - 15, 2 * R_BOLA - 2), 30, Z_CHASIS - 2 * R_BOLA + 2, fc="0.75", ec="k"))
    a2.add_patch(Rectangle((X_VASO - R_EXT_VASO, Z_PISO2 + T_PISO2), 2 * R_EXT_VASO, H_PORTAVASO,
                           fc=COLORES["portavaso"], ec="k", alpha=0.8))
    a2.add_patch(Rectangle((X_VASO - 35, Z_PISO2 + T_PISO2 + 2), 70, 75, fc="none", ec="0.4", ls=":"))
    a2.text(X_VASO, Z_PISO2 + 85, "vaso Ø70", ha="center", fontsize=8, color="0.3")
    for nombre, (cx, cy, sx, sy, sz, z0, color) in COMPONENTES.items():
        a2.add_patch(Rectangle((cx - sx / 2, z0), sx, sz, fc=color, ec="k", alpha=0.5))
    for s, x in HCSR04:
        a2.add_patch(Rectangle((x - 1, Z_HCSR04 - 10), 2, 20, fc=COLORES["sensor"], ec="k"))
        a2.add_patch(Rectangle((x + (0 if s > 0 else -12), Z_HCSR04 - 8), 12, 16, fc=COLORES["transductor"], ec="k"))
    a2.plot([-170, 190], [0, 0], "k-", lw=2)
    altura = Z_PISO2 + T_PISO2 + H_PORTAVASO
    cota(a2, (150, 0), (150, altura), f"{altura:.0f}", off=(14, 0))
    cota(a2, (-150, 0), (-150, Z_CHASIS), f"{Z_CHASIS:.0f}", off=(-14, 0))
    cota(a2, (X_EJE - R_RUEDA, -15), (X_EJE + R_RUEDA, -15), f"Ø{2 * R_RUEDA:.0f}")
    a2.set_xlim(-170, 190); a2.set_ylim(-35, 190); a2.set_aspect("equal"); a2.grid(alpha=0.2)
    a2.set_xlabel("X (adelante →)"); a2.set_ylabel("Z")
    plt.tight_layout()
    plt.savefig(ruta, dpi=130, bbox_inches="tight")
    plt.close(fig)

if __name__ == "__main__":
    ap = argparse.ArgumentParser()
    ap.add_argument("--escala", type=float, default=4.0, help="escala del URDF (la simulación usa 4)")
    args = ap.parse_args()
    generar_scad(os.path.join(AQUI, "carro.scad"))
    n = generar_stl(os.path.join(AQUI, "carro_ensamble.stl"))
    generar_urdf(os.path.join(AQUI, "carro.urdf"), args.escala)
    generar_plano(os.path.join(AQUI, "plano_carro.png"))
    print("carro.scad, carro_ensamble.stl (%d triangulos), carro.urdf (escala %g) y plano_carro.png generados"
          % (n, args.escala))
```

</details>

<details>
<summary><b>Código: <code>6_cad/carro.scad</code></b> (CAD paramétrico de OpenSCAD)</summary>

```openscad
// carro.scad - Carro recolector de vasos (Grupo 5) - cotas en mm
// Generado por generar_cad.py. Abrir en OpenSCAD: F5 vista previa, F6 render, F7 exportar STL.
// Cambia "pieza" para exportar cada parte imprimible por separado.

pieza = "ensamble";   // "ensamble", "chasis", "piso2", "portavaso", "soporte_sensor"
$fn = 64;

L = 220.0; W = 140.0;
t_chasis = 4.0; z_chasis = 42.0;
r_rueda = 32.5; a_rueda = 26.0;
x_eje = -30.0; y_rueda = 86.0;
x_loca = 85.0; r_bola = 10.0;
h_sep = 40.0; t_piso2 = 3.0;
z_piso2 = z_chasis + t_chasis + h_sep;
x_vaso = -55.0; r_ext_vaso = 43.0; r_int_vaso = 39.0; h_portavaso = 30.0;
r_esquina = 10;

module placa_redondeada(l, w, t, r) {
    hull() for (sx = [-1, 1], sy = [-1, 1])
        translate([sx * (l / 2 - r), sy * (w / 2 - r), 0]) cylinder(r = r, h = t);
}

// Chasis inferior: agujeros para separadores, rueda loca, motores y paso de cables
module chasis() {
    difference() {
        placa_redondeada(L, W, t_chasis, r_esquina);
        for (sx = [-1, 1], sy = [-1, 1])
            translate([sx * (L / 2 - 15), sy * (W / 2 - 10), -1]) cylinder(d = 3.4, h = t_chasis + 2);
        for (dx = [-10, 10], dy = [-10, 10])                 // rueda loca
            translate([x_loca + dx, dy, -1]) cylinder(d = 3.4, h = t_chasis + 2);
        for (s = [-1, 1], dx = [-8, 8])                      // soportes de motor
            translate([x_eje + dx, s * 40, -1]) cylinder(d = 3.4, h = t_chasis + 2);
        translate([0, 0, -1]) linear_extrude(t_chasis + 2)   // paso de cables
            hull() { translate([-10, 0]) circle(d = 14); translate([10, 0]) circle(d = 14); }
        for (y = [-20, 0, 20])                                // sensores IR de linea
            translate([L / 2 - 12, y, -1]) cylinder(d = 3.4, h = t_chasis + 2);
    }
}

// Chasis superior con agujero para el porta-vaso y ventilacion
module piso2() {
    difference() {
        placa_redondeada(L, W, t_piso2, r_esquina);
        for (sx = [-1, 1], sy = [-1, 1])
            translate([sx * (L / 2 - 15), sy * (W / 2 - 10), -1]) cylinder(d = 3.4, h = t_piso2 + 2);
        for (i = [0 : 3])
            translate([20 + i * 18, -25, -1]) cube([10, 50, t_piso2 + 2]);
    }
}

// Porta-vaso: tubo con base, recibe un vaso de 70 mm
module portavaso() {
    difference() {
        union() {
            cylinder(r = r_ext_vaso, h = h_portavaso);
            cylinder(r = r_ext_vaso + 6, h = 2);             // pestaña de apoyo
        }
        translate([0, 0, 2]) cylinder(r = r_int_vaso, h = h_portavaso);
        translate([0, 0, -1]) cylinder(r = r_int_vaso - 8, h = 4);
        translate([-r_ext_vaso - 1, -8, 12]) cube([10, 16, h_portavaso]);   // ranura sensor
    }
}

// Soporte en L para el HC-SR04
module soporte_sensor() {
    difference() {
        union() {
            translate([-2, -25, 0]) cube([2, 50, 26]);
            translate([-14, -25, 0]) cube([14, 50, 2]);
        }
        for (y = [-13, 13]) translate([-3, y, 16]) rotate([0, 90, 0]) cylinder(d = 16.5, h = 4);
        for (y = [-18, 18]) translate([-7, y, -1]) cylinder(d = 3.4, h = 4);
    }
}

module rueda() { rotate([90, 0, 0]) cylinder(r = r_rueda, h = a_rueda, center = true); }
module motor_tt() { cube([22.5, 65, 18.8], center = true); }

module ensamble() {
    color("orange") translate([0, 0, z_chasis]) chasis();
    color("gainsboro") translate([0, 0, z_piso2]) piso2();
    color("goldenrod") for (sx = [-1, 1], sy = [-1, 1])
        translate([sx * (L / 2 - 15), sy * (W / 2 - 10), z_chasis + t_chasis]) cylinder(r = 3, h = h_sep);
    for (s = [-1, 1]) {
        color("gold") translate([x_eje, s * (5 + 65 / 2), z_chasis - 18.8 / 2]) motor_tt();
        color("black") translate([x_eje, s * y_rueda, r_rueda]) rueda();
    }
    color("silver") translate([x_loca, 0, r_bola]) sphere(r = r_bola);
    color("silver") translate([x_loca - 15, -15, 2 * r_bola - 2]) cube([30, 30, z_chasis - 2 * r_bola + 2]);
    color("dodgerblue") translate([x_vaso, 0, z_piso2 + t_piso2]) portavaso();
    color("steelblue") translate([L / 2, 0, z_chasis + t_chasis]) soporte_sensor();
    color("steelblue") translate([-L / 2, 0, z_chasis + t_chasis]) mirror([1, 0, 0]) soporte_sensor();
    color([0.1, 0.1, 0.12]) translate([0.5, 19.0, 46.0]) cube([69.0, 26.0, 10.0]);  // esp32_s3
    color([0.75, 0.1, 0.1]) translate([24.5, -38.0, 46.0]) cube([21.0, 20.0, 8.0]);  // tb6612
    color([0.15, 0.15, 0.55]) translate([-68.5, -20.5, 46.0]) cube([77.0, 41.0, 21.0]);  // bateria
    color([0.1, 0.35, 0.65]) translate([50.5, -48.5, 46.0]) cube([43.0, 21.0, 14.0]);  // buck_5v
}

if (pieza == "ensamble") ensamble();
if (pieza == "chasis") chasis();
if (pieza == "piso2") piso2();
if (pieza == "portavaso") portavaso();
if (pieza == "soporte_sensor") soporte_sensor();
```

</details>

---

## 8. Diseño electrónico: pines y esquemas

### ESP32-S3 #1 — Estación

| Elemento | Pin del módulo | GPIO ESP32-S3 |
|---|---|---|
| ULN2003 (banda) | IN1 / IN2 / IN3 / IN4 | 4 / 5 / 6 / 7 |
| A4988 (cadena) | STEP / DIR / EN | 15 / 16 / 17 |
| TCRT5000 (home cadena) | DO | 18 |
| FC-51 (moneda en inspección) | OUT | 1 |
| Servo compuerta | Señal | 10 |
| Servo empujador | Señal | 13 |
| HX711 | DT / SCK | 11 / 12 |

```text
 12 V ──┬── A4988 VMOT (+100 µF) ── NEMA 17 (bobinas 1A1B / 2A2B)
        └── LM2596 ── 5 V ──┬── ULN2003 (+) ── 28BYJ-48
                            ├── Servos (rojo)            * Señales: ESP32 → servo (naranja)
                            ├── ESP32-S3 (pin 5V)
                            └── FC-51, TCRT5000, HX711 (VCC 3V3 de la ESP32)
 GND común: fuente, A4988, ULN2003, servos, sensores y ESP32-S3
 A4988: MS1=1, MS2=1, MS3=0 (1/8 de paso); VDD = 3V3; ajustar Vref según el NEMA 17
```

### ESP32-S3 #2 — Carro

| Elemento | Pin del módulo | GPIO ESP32-S3 |
|---|---|---|
| TB6612FNG motor izquierdo | AIN1 / AIN2 / PWMA | 4 / 5 / 6 |
| TB6612FNG motor derecho | BIN1 / BIN2 / PWMB | 7 / 15 / 16 |
| TB6612FNG | STBY | 17 |
| HC-SR04 frontal | TRIG / ECHO* | 1 / 2 |
| HC-SR04 trasero | TRIG / ECHO* | 41 / 42 |
| TCRT5000 izquierdo / centro / derecho | DO | 8 / 9 / 10 |
| Buzzer | + | 18 |

\* **ECHO con divisor de tensión** (1 kΩ en serie y 2 kΩ a GND): el HC-SR04 entrega 5 V y la ESP32-S3 soporta 3,3 V.

```text
 2×18650 (7,4 V) ── interruptor ──┬── TB6612 VM ── AO1/AO2: motor izq · BO1/BO2: motor der
                                  └── MP1584 ── 5 V ──┬── ESP32-S3 (pin 5V)
                                                      └── HC-SR04 ×2 (VCC)
 TB6612 VCC y TCRT5000 VCC ── 3V3 de la ESP32-S3
 HC-SR04 ECHO ──[1 kΩ]──┬── GPIO 2 / 42
                        └──[2 kΩ]── GND
 GND común en todo el carro
```

---

## 9. Identificación visual de monedas

### Monedas en circulación (Banco de la República, familia 2012)

| Moneda | Diámetro | Peso | Anillo | Centro |
|---|---|---|---|---|
| $50 | 17,0 mm | 2,00 g | plateado | plateado |
| $100 | 20,3 mm | 3,34 g | dorado | dorado |
| $200 | 22,4 mm | 4,61 g | plateado | plateado |
| $500 | 23,7 mm | 7,14 g | plateado | **dorado** (bimetálica) |
| $1000 | 26,7 mm | 9,95 g | **dorado** | plateado (bimetálica) |

### Método

1. **Segmentación por brillo (canal V de HSV).** Sobre la banda negra, cualquier moneda, dorada o plateada, es mucho más clara. El umbral fijo (V > 80) resultó más robusto que Otsu cuando entran en la imagen bordes claros.
2. **Contornos** filtrados por área (radio entre 7 y 16 mm) y **circularidad** > 0,75.
3. **Diámetro equivalente** = 2·√(área/π), convertido a mm con la calibración px/mm. Para calibrar, se pone una moneda de $1000 y se presiona `c`.
4. **Color**: la mediana de tono (H) y saturación (S) en el **centro** (r < 0,35R) y en el **anillo** (0,78R–0,92R). Es "oro" si S ≥ 70 y 8 ≤ H ≤ 40.
5. **Clasificación por costo mínimo**: `|Ø − Ø_ref| / 0,6 mm + 2·(color de centro distinto) + 2·(color de anillo distinto)`. Si el costo es mayor que 3, la moneda es **desconocida** y va al vaso de rechazo.

El color es lo que separa las monedas de tamaño parecido: **$200** (23,7 − 22,4 = 1,3 mm de diferencia con la de $500) es toda plateada, y **$500** tiene el centro dorado.

Cámara de inspección simulada

<details>
<summary><b>Código: <code>1_vision/vision_monedas.py</code></b></summary>

```python
"""
vision_monedas.py  -  Identificación visual de monedas colombianas (PC)

Una cámara cenital mira la "zona de inspección" de la banda transportadora
(banda NEGRA para dar contraste). Cuando una moneda se detiene bajo la cámara:
  1. Se segmenta por brillo (moneda clara sobre banda oscura) y contornos.
  2. Se mide su diámetro en mm (con la calibración px/mm).
  3. Se mide el color del centro y del anillo (dorado o plateado) en HSV.
  4. Se elige la denominación que mejor coincide (diámetro + colores).
  5. Se envía el resultado a la ESP32 de la estación por Wi-Fi (HTTP).

Las mismas funciones las usa la simulación de PyBullet con su cámara virtual.

Uso:
  python vision_monedas.py --ip 192.168.1.50          (sistema real)
  python vision_monedas.py --sin-esp                   (solo ver la clasificación)
  python vision_monedas.py --calibrar 1000             (poner una moneda de $1000 y calibrar)
"""

import argparse
import json
import os
import time
import urllib.request

import cv2
import numpy as np

AQUI = os.path.dirname(os.path.abspath(__file__))
ARCHIVO_CALIBRACION = os.path.join(AQUI, "calibracion.json")

# Monedas en circulación (Banco de la República, familia 2012)
MONEDAS = {
    50:   {"diametro": 17.0, "peso": 2.00, "anillo": "plata", "centro": "plata"},
    100:  {"diametro": 20.3, "peso": 3.34, "anillo": "oro",   "centro": "oro"},
    200:  {"diametro": 22.4, "peso": 4.61, "anillo": "plata", "centro": "plata"},
    500:  {"diametro": 23.7, "peso": 7.14, "anillo": "plata", "centro": "oro"},
    1000: {"diametro": 26.7, "peso": 9.95, "anillo": "oro",   "centro": "plata"},
}

TOLERANCIA_MM = 0.6      # error de diámetro que vale "1 punto" en el costo
UMBRAL_SATURACION = 70   # S (0-255) a partir de la cual un tono amarillo es "oro"
UMBRAL_BRILLO = 80       # V (0-255): lo más claro que esto es moneda (banda negra). None = Otsu
COSTO_MAXIMO = 3.0       # por encima de esto la moneda se marca como desconocida

# ---------------------------------------------------------------------------
# Funciones de visión (las usa también la simulación)
# ---------------------------------------------------------------------------
def segmentar(frame_bgr, px_por_mm):
    """Devuelve una lista de monedas candidatas: (cx, cy, radio_px, contorno)."""
    # Brillo (canal V): las monedas, doradas o plateadas, son mucho más claras que la banda negra
    brillo = cv2.GaussianBlur(cv2.cvtColor(frame_bgr, cv2.COLOR_BGR2HSV)[..., 2], (5, 5), 0)
    if UMBRAL_BRILLO is None:
        _, binaria = cv2.threshold(brillo, 0, 255, cv2.THRESH_BINARY + cv2.THRESH_OTSU)
    else:
        _, binaria = cv2.threshold(brillo, UMBRAL_BRILLO, 255, cv2.THRESH_BINARY)
    nucleo = np.ones((5, 5), np.uint8)
    binaria = cv2.morphologyEx(binaria, cv2.MORPH_OPEN, nucleo)
    binaria = cv2.morphologyEx(binaria, cv2.MORPH_CLOSE, nucleo)   # tapa reflejos dentro de la moneda
    contornos, _ = cv2.findContours(binaria, cv2.RETR_EXTERNAL, cv2.CHAIN_APPROX_NONE)
    r_min = 7.0 * px_por_mm       # una moneda de $50 tiene radio 8,5 mm
    r_max = 16.0 * px_por_mm      # una de $1000 tiene radio 13,35 mm
    monedas = []
    for c in contornos:
        area = cv2.contourArea(c)
        if area < np.pi * r_min ** 2 or area > np.pi * r_max ** 2:
            continue
        perimetro = cv2.arcLength(c, True)
        circularidad = 4 * np.pi * area / (perimetro ** 2 + 1e-9)
        if circularidad < 0.75:
            continue
        (cx, cy), _ = cv2.minEnclosingCircle(c)
        radio = np.sqrt(area / np.pi)          # radio equivalente por área (más estable)
        monedas.append((cx, cy, radio, c))
    return monedas

def color_zona(hsv, cx, cy, r_in, r_out):
    """'oro' o 'plata' según la mediana de tono y saturación en un anillo."""
    h, w = hsv.shape[:2]
    yy, xx = np.ogrid[:h, :w]
    d2 = (xx - cx) ** 2 + (yy - cy) ** 2
    mascara = (d2 >= r_in ** 2) & (d2 <= r_out ** 2)
    if not mascara.any():
        return "plata", 0, 0
    tono = float(np.median(hsv[..., 0][mascara]))
    sat = float(np.median(hsv[..., 1][mascara]))
    es_oro = sat >= UMBRAL_SATURACION and 8 <= tono <= 40
    return ("oro" if es_oro else "plata"), tono, sat

def clasificar(diametro_mm, color_centro, color_anillo):
    """Denominación más probable y su costo (menor = mejor)."""
    mejor, costo_min = None, 1e9
    for valor, m in MONEDAS.items():
        costo = abs(diametro_mm - m["diametro"]) / TOLERANCIA_MM
        costo += 2.0 * (color_centro != m["centro"]) + 2.0 * (color_anillo != m["anillo"])
        if costo < costo_min:
            mejor, costo_min = valor, costo
    if costo_min > COSTO_MAXIMO:
        return None, costo_min
    return mejor, costo_min

def analizar(frame_bgr, px_por_mm):
    """Detecta y clasifica todas las monedas de la imagen.
    Devuelve una lista de diccionarios con valor, diámetro, colores y posición."""
    hsv = cv2.cvtColor(frame_bgr, cv2.COLOR_BGR2HSV)
    resultados = []
    for cx, cy, r, contorno in segmentar(frame_bgr, px_por_mm):
        diametro = float(2 * r / px_por_mm)
        c_centro, h1, s1 = color_zona(hsv, cx, cy, 0, 0.35 * r)
        c_anillo, h2, s2 = color_zona(hsv, cx, cy, 0.78 * r, 0.92 * r)
        valor, costo = clasificar(diametro, c_centro, c_anillo)
        resultados.append({"valor": valor, "diametro": round(diametro, 2), "centro": c_centro,
                           "anillo": c_anillo, "costo": round(costo, 2), "x": cx, "y": cy, "r": r,
                           "peso": MONEDAS[valor]["peso"] if valor else 0.0})
    return resultados

def dibujar(frame, resultados):
    for m in resultados:
        color = (0, 200, 0) if m["valor"] else (0, 0, 255)
        cv2.circle(frame, (int(m["x"]), int(m["y"])), int(m["r"]), color, 2)
        texto = ("$%d" % m["valor"]) if m["valor"] else "?"
        cv2.putText(frame, "%s  %.1f mm  %s/%s" % (texto, m["diametro"], m["centro"], m["anillo"]),
                    (int(m["x"] - m["r"]), int(m["y"] - m["r"] - 8)),
                    cv2.FONT_HERSHEY_SIMPLEX, 0.5, color, 2)
    return frame

# ---------------------------------------------------------------------------
# Programa principal (cámara real)
# ---------------------------------------------------------------------------
def cargar_calibracion():
    if os.path.isfile(ARCHIVO_CALIBRACION):
        with open(ARCHIVO_CALIBRACION) as f:
            return json.load(f)["px_por_mm"]
    return 10.0

def enviar_estacion(ip, resultado):
    url = "http://%s/moneda?valor=%d&diametro=%.2f" % (ip, resultado["valor"], resultado["diametro"])
    try:
        with urllib.request.urlopen(url, timeout=2) as r:
            return r.read().decode()
    except Exception as e:
        return "ERROR: %s" % e

def main():
    ap = argparse.ArgumentParser(description="Identificación de monedas con OpenCV")
    ap.add_argument("--camara", type=int, default=0)
    ap.add_argument("--ip", default="192.168.1.50", help="IP de la ESP32 de la estación")
    ap.add_argument("--sin-esp", action="store_true")
    ap.add_argument("--calibrar", type=int, choices=list(MONEDAS), help="moneda de referencia")
    args = ap.parse_args()

    px_por_mm = cargar_calibracion()
    cap = cv2.VideoCapture(args.camara)
    estable, ultimo, enviado, vacio = 0, None, False, 0
    print("px/mm = %.2f  (q = salir, c = calibrar con --calibrar)" % px_por_mm)

    while cap.isOpened():
        ok, frame = cap.read()
        if not ok:
            break
        h, w = frame.shape[:2]
        # Zona de inspección: el tercio central de la imagen
        x0, x1 = w // 3, 2 * w // 3
        roi = frame[:, x0:x1]
        resultados = analizar(roi, px_por_mm)
        for m in resultados:
            m["x"] += x0
        cv2.rectangle(frame, (x0, 0), (x1, h - 1), (255, 200, 0), 1)
        dibujar(frame, resultados)

        if args.calibrar and len(resultados) == 1:
            cv2.putText(frame, "c = calibrar con moneda de $%d" % args.calibrar, (10, 25),
                        cv2.FONT_HERSHEY_SIMPLEX, 0.7, (255, 255, 0), 2)

        # Una sola moneda, estable durante 5 cuadros -> se envía una vez
        if len(resultados) == 1 and resultados[0]["valor"]:
            vacio = 0
            v = resultados[0]["valor"]
            estable = estable + 1 if v == ultimo else 1
            ultimo = v
            if estable >= 5 and not enviado and not args.calibrar:
                respuesta = "sin ESP" if args.sin_esp else enviar_estacion(args.ip, resultados[0])
                print("Moneda $%d (%.1f mm) -> %s" % (v, resultados[0]["diametro"], respuesta))
                enviado = True
        elif not resultados:
            vacio += 1
            if vacio > 10:            # la moneda ya salió de la zona
                enviado, estable, ultimo = False, 0, None

        cv2.imshow("Monedas - zona de inspeccion", frame)
        tecla = cv2.waitKey(1) & 0xFF
        if tecla == ord("q"):
            break
        if tecla == ord("c") and args.calibrar and len(resultados) == 1:
            d_px = 2 * resultados[0]["r"]
            px_por_mm = d_px / MONEDAS[args.calibrar]["diametro"]
            with open(ARCHIVO_CALIBRACION, "w") as f:
                json.dump({"px_por_mm": px_por_mm}, f)
            print("Calibrado: %.3f px/mm guardado en calibracion.json" % px_por_mm)

    cap.release()
    cv2.destroyAllWindows()

if __name__ == "__main__":
    main()
```

</details>

---

## 10. Firmware de las ESP32-S3

Las dos placas usan **MicroPython** con `asyncio`. Un servidor HTTP atiende a la app mientras el bucle de control mueve los motores sin bloquearse.

### API HTTP

| Placa | Ruta | Acción |
|---|---|---|
| Estación | `GET /estado` | JSON con conteo, valor, peso, vasos, última moneda y estado |
| Estación | `GET /moneda?valor=500` | Resultado de la visión: clasifica la moneda retenida |
| Estación | `GET /entregar?valor=500` | Lleva ese vaso a la entrega, lo pesa y lo empuja al carro (sin valor: el de más dinero) |
| Estación | `GET /home`, `GET /tara` | Referencia de la cadena y cero de la balanza |
| Carro | `GET /cmd?c=estacionar` | Orden: `estacionar`, `meta`, `alto`, `adelante`, `atras`, `izquierda`, `derecha` |
| Carro | `GET /estado` | Modo, mensaje, distancias, sensores de línea y velocidades |

### Lógica del carro

| Modo | Comportamiento |
|---|---|
| `ESTACIONANDO` | Reversa (−45 % y −28 % de PWM al acercarse), corrige el rumbo con la guía de línea y pita cada vez más rápido; se detiene a **6 cm** |
| `LINEA` | Seguidor de línea con 3 sensores; con los tres en negro (franja de meta) pasa a `EN_META` |
| `ESQUIVANDO` | Si hay obstáculo a menos de 18 cm: gira, avanza, regresa y busca la línea (lado según `LADOS_ESQUIVE`) |
| `MANUAL` | Movimientos temporizados (1 s recto, 0,45 s de giro) y con parada por obstáculo |

Todos los cambios de velocidad pasan por una **rampa** (máx. 8 % de PWM cada 20 ms), lo que da arranques y frenadas suaves.

<details>
<summary><b>Código: <code>2_estacion_esp32/main.py</code></b> (estación)</summary>

```python
# main.py  -  ESP32-S3 "ESTACION" (MicroPython)
# Banda transportadora + compuerta de inspección + selector en cadena de vasos
# + empujador hacia el carro + celda de carga. Servidor HTTP por Wi-Fi.
#
# Flujo:
#   1. La banda (28BYJ-48) avanza hasta que el sensor IR detecta una moneda
#      bajo la cámara; la compuerta (servo) la retiene.
#   2. El PC (vision_monedas.py) la identifica y llama  /moneda?valor=500
#   3. La cadena (NEMA 17 + A4988) gira hasta dejar el vaso de $500 bajo la caída.
#   4. La compuerta se abre, la banda lleva la moneda al final y cae en su vaso.
#   5. /entregar?valor=500 lleva ese vaso al puesto de entrega, lo pesa (HX711)
#      y el empujador (servo) lo pasa al porta-vaso del carro.
#
# Rutas HTTP:  /estado   /moneda?valor=V   /entregar?valor=V   /home   /tara

import asyncio
import json
import time
import network
from machine import Pin, PWM

# ------------------------------------------------------------------ CONFIGURACION
WIFI_SSID = "MI_RED"
WIFI_CLAVE = "MI_CLAVE"
AP_SSID, AP_CLAVE = "Estacion-Monedas", "12345678"   # si no hay red, crea su propio Wi-Fi

PINES_BANDA = (4, 5, 6, 7)        # ULN2003 IN1..IN4 (28BYJ-48)
PIN_STEP, PIN_DIR, PIN_EN = 15, 16, 17    # A4988 de la cadena (NEMA 17)
PIN_HOME_CADENA = 18              # sensor optico TCRT5000 en el puesto 0 (activo en bajo)
PIN_SENSOR_MONEDA = 1             # sensor IR FC-51 bajo la camara (activo en bajo)
PIN_SERVO_COMPUERTA = 10
PIN_SERVO_EMPUJADOR = 13
PIN_HX711_DT, PIN_HX711_SCK = 11, 12

PUESTOS = [50, 100, 200, 500, 1000, "rechazo"]   # orden de los vasos en la cadena
PUESTO_ENTREGA = 3                # la entrega esta 3 puestos despues de la caida
DIST_VASOS_MM, DIAM_PINON_MM, MICROPASOS = 195, 40, 8
PASOS_POR_PUESTO = int(DIST_VASOS_MM / (3.1416 * DIAM_PINON_MM) * 200 * MICROPASOS)   # = 2483
PASOS_VUELTA = PASOS_POR_PUESTO * len(PUESTOS)
T_CAIDA_MS = 4500                 # banda ~19 mm/s: la camara esta a 75 mm del final
T_SIN_VISION_MS = 5000            # si el PC no responde, la moneda va a "rechazo"
PESOS = {50: 2.00, 100: 3.34, 200: 4.61, 500: 7.14, 1000: 9.95}   # gramos
ESCALA_HX711 = 420.0              # cuentas por gramo (calibrar con un peso conocido)

# ------------------------------------------------------------------ ACTUADORES
class PasoAPaso28BYJ:
    SECUENCIA = ((1, 0, 0, 0), (1, 1, 0, 0), (0, 1, 0, 0), (0, 1, 1, 0),
                 (0, 0, 1, 0), (0, 0, 1, 1), (0, 0, 0, 1), (1, 0, 0, 1))

    def __init__(self, pines):
        self.bobinas = [Pin(n, Pin.OUT, value=0) for n in pines]
        self.i = 0

    def paso(self):
        self.i = (self.i + 1) % 8
        for b, v in zip(self.bobinas, self.SECUENCIA[self.i]):
            b.value(v)

    def liberar(self):
        for b in self.bobinas:
            b.value(0)

class PasoAPasoA4988:
    def __init__(self, step, dire, en):
        self.step = Pin(step, Pin.OUT, value=0)
        self.dir = Pin(dire, Pin.OUT, value=0)
        self.en = Pin(en, Pin.OUT, value=1)       # 1 = deshabilitado
        self.posicion = 0                          # pasos (0 = vaso de $50 en la caida)

    async def mover(self, pasos, us_min=350, us_max=1400):
        """Movimiento con rampa trapezoidal (arranca y frena suave)."""
        if pasos == 0:
            return
        self.en.value(0)
        self.dir.value(1 if pasos > 0 else 0)
        n = abs(pasos)
        rampa = min(300, n // 2)
        for k in range(n):
            d = min(k, n - 1 - k)
            us = us_max - (us_max - us_min) * min(d, rampa) // max(rampa, 1)
            self.step.value(1)
            time.sleep_us(4)
            self.step.value(0)
            time.sleep_us(us)
            if k % 200 == 0:
                await asyncio.sleep_ms(0)          # deja atender al servidor web
        self.posicion = (self.posicion + pasos) % PASOS_VUELTA
        self.en.value(1)

class Servo:
    def __init__(self, pin, angulo=0):
        self.pwm = PWM(Pin(pin), freq=50)
        self.angulo(angulo)

    def angulo(self, a):
        us = 500 + 2000 * max(0, min(180, a)) // 180
        self.pwm.duty_u16(us * 65535 // 20000)

class HX711:
    def __init__(self, dt, sck):
        self.dt = Pin(dt, Pin.IN)
        self.sck = Pin(sck, Pin.OUT, value=0)
        self.cero = 0

    def crudo(self):
        t0 = time.ticks_ms()
        while self.dt.value():
            if time.ticks_diff(time.ticks_ms(), t0) > 200:
                return None                     # sin celda conectada
        v = 0
        for _ in range(24):
            self.sck.value(1)
            v = (v << 1) | self.dt.value()
            self.sck.value(0)
        self.sck.value(1)                       # pulso 25: ganancia 128
        self.sck.value(0)
        if v & 0x800000:
            v -= 1 << 24
        return v

    def promedio(self, n=8):
        datos = [x for x in (self.crudo() for _ in range(n)) if x is not None]
        return sum(datos) / len(datos) if datos else None

    def tara(self):
        v = self.promedio(16)
        self.cero = v if v is not None else 0

    def gramos(self):
        v = self.promedio()
        return None if v is None else round((v - self.cero) / ESCALA_HX711, 2)

# ------------------------------------------------------------------ ESTADO
banda = PasoAPaso28BYJ(PINES_BANDA)
cadena = PasoAPasoA4988(PIN_STEP, PIN_DIR, PIN_EN)
home_cadena = Pin(PIN_HOME_CADENA, Pin.IN, Pin.PULL_UP)
sensor_moneda = Pin(PIN_SENSOR_MONEDA, Pin.IN, Pin.PULL_UP)
compuerta = Servo(PIN_SERVO_COMPUERTA, 0)        # 0 = cerrada, 90 = abierta
empujador = Servo(PIN_SERVO_EMPUJADOR, 0)        # 0 = recogido, 120 = empuja
balanza = HX711(PIN_HX711_DT, PIN_HX711_SCK)

estado = {
    "estado": "BANDA",            # BANDA, ESPERANDO_VISION, CLASIFICANDO, ENTREGANDO
    "conteo": {str(v): 0 for v in PESOS},
    "rechazadas": 0,
    "vasos": {str(v): {"monedas": 0, "valor": 0, "peso": 0.0} for v in PUESTOS},
    "ultima": None,
    "peso_medido_g": None,
    "ip": "",
}
t_espera = 0
ocupado = False

def resumen():
    total = sum(int(k) * n for k, n in estado["conteo"].items())
    peso = sum(PESOS[int(k)] * n for k, n in estado["conteo"].items())
    r = dict(estado)
    r["valor_total"] = total
    r["peso_total_g"] = round(peso, 2)
    r["monedas_total"] = sum(estado["conteo"].values())
    return r

async def ir_a_puesto(indice_vaso, puesto):
    """Gira la cadena para que el vaso 'indice_vaso' quede en 'puesto' (camino mas corto)."""
    objetivo = ((puesto - indice_vaso) * PASOS_POR_PUESTO) % PASOS_VUELTA
    delta = (objetivo - cadena.posicion + PASOS_VUELTA // 2) % PASOS_VUELTA - PASOS_VUELTA // 2
    await cadena.mover(delta)

async def clasificar(valor):
    """Lleva el vaso correcto a la caida y suelta la moneda."""
    global ocupado
    ocupado = True
    estado["estado"] = "CLASIFICANDO"
    etiqueta = valor if valor in PESOS else "rechazo"
    await ir_a_puesto(PUESTOS.index(etiqueta), 0)
    compuerta.angulo(90)                          # abre la compuerta
    t0 = time.ticks_ms()
    while time.ticks_diff(time.ticks_ms(), t0) < T_CAIDA_MS:
        banda.paso()
        if time.ticks_diff(time.ticks_ms(), t0) > 800:
            compuerta.angulo(0)                   # la cierra para la siguiente
        await asyncio.sleep_ms(1)
    v = estado["vasos"][str(etiqueta)]
    v["monedas"] += 1
    if etiqueta == "rechazo":
        estado["rechazadas"] += 1
    else:
        estado["conteo"][str(etiqueta)] += 1
        v["valor"] += etiqueta
        v["peso"] = round(v["peso"] + PESOS[etiqueta], 2)
    estado["ultima"] = {"valor": valor, "t": time.ticks_ms()}
    estado["estado"] = "BANDA"
    ocupado = False

async def entregar(valor):
    """Lleva el vaso al puesto de entrega, lo pesa y lo empuja al carro."""
    global ocupado
    ocupado = True
    estado["estado"] = "ENTREGANDO"
    etiqueta = valor if valor in PESOS else "rechazo"
    await ir_a_puesto(PUESTOS.index(etiqueta), PUESTO_ENTREGA)
    await asyncio.sleep_ms(500)
    estado["peso_medido_g"] = balanza.gramos()
    for a in range(0, 121, 4):                    # empuje suave
        empujador.angulo(a)
        await asyncio.sleep_ms(25)
    await asyncio.sleep_ms(400)
    empujador.angulo(0)
    estado["vasos"][str(etiqueta)] = {"monedas": 0, "valor": 0, "peso": 0.0}   # vaso nuevo vacio
    estado["estado"] = "BANDA"
    ocupado = False

async def hacer_home():
    global ocupado
    ocupado = True
    estado["estado"] = "HOME"
    cadena.en.value(0)
    cadena.dir.value(0)
    for _ in range(PASOS_VUELTA + PASOS_POR_PUESTO):
        if home_cadena.value() == 0:
            break
        cadena.step.value(1)
        time.sleep_us(4)
        cadena.step.value(0)
        time.sleep_us(1200)
    cadena.en.value(1)
    cadena.posicion = 0
    estado["estado"] = "BANDA"
    ocupado = False

# ------------------------------------------------------------------ TAREAS
async def tarea_banda():
    """Avanza la banda hasta que una moneda llega a la zona de inspeccion."""
    global t_espera
    while True:
        if estado["estado"] == "BANDA" and not ocupado:
            if sensor_moneda.value() == 0:            # moneda bajo la camara
                banda.liberar()
                estado["estado"] = "ESPERANDO_VISION"
                t_espera = time.ticks_ms()
            else:
                banda.paso()
            await asyncio.sleep_ms(1)                 # 1 ms por medio paso: ~19 mm/s con rodillo de 25 mm
        elif estado["estado"] == "ESPERANDO_VISION":
            if time.ticks_diff(time.ticks_ms(), t_espera) > T_SIN_VISION_MS:
                estado["estado"] = "CLASIFICANDO"
                asyncio.create_task(clasificar(None))  # sin respuesta: a rechazo
            await asyncio.sleep_ms(50)
        else:
            await asyncio.sleep_ms(50)

def parsear(ruta):
    if "?" not in ruta:
        return ruta, {}
    camino, q = ruta.split("?", 1)
    args = {}
    for par in q.split("&"):
        if "=" in par:
            k, v = par.split("=", 1)
            args[k] = v.replace("+", " ").replace("%20", " ")
    return camino, args

def manejar(ruta):
    camino, args = parsear(ruta)
    if camino == "/estado":
        return "200 OK", resumen()
    if camino == "/moneda":
        if estado["estado"] != "ESPERANDO_VISION":
            return "409 Conflict", {"error": "no hay moneda esperando", "estado": estado["estado"]}
        try:
            valor = int(args.get("valor", "0"))
        except ValueError:
            valor = None
        estado["estado"] = "CLASIFICANDO"
        asyncio.create_task(clasificar(valor if valor in PESOS else None))
        return "200 OK", {"ok": True, "valor": valor}
    if camino == "/entregar":
        if ocupado:
            return "409 Conflict", {"error": "ocupada", "estado": estado["estado"]}
        try:
            valor = int(args.get("valor", "0"))
        except ValueError:
            valor = 0
        if valor not in PESOS:      # sin valor: el vaso con mas dinero
            valor = max(PESOS, key=lambda v: estado["vasos"][str(v)]["valor"])
        estado["estado"] = "ENTREGANDO"
        asyncio.create_task(entregar(valor))
        return "200 OK", {"ok": True, "vaso": valor, "contenido": estado["vasos"][str(valor)]}
    if camino == "/home":
        asyncio.create_task(hacer_home())
        return "200 OK", {"ok": True}
    if camino == "/tara":
        balanza.tara()
        return "200 OK", {"ok": True}
    return "404 Not Found", {"rutas": ["/estado", "/moneda?valor=", "/entregar?valor=", "/home", "/tara"]}

async def atender(lector, escritor):
    try:
        linea = await lector.readline()
        partes = linea.decode().split(" ")
        ruta = partes[1] if len(partes) > 1 else "/"
        while True:                                   # descartar cabeceras
            h = await lector.readline()
            if not h or h == b"\r\n":
                break
        codigo, cuerpo = manejar(ruta)
        escritor.write(("HTTP/1.1 %s\r\nContent-Type: application/json\r\n"
                        "Access-Control-Allow-Origin: *\r\nConnection: close\r\n\r\n" % codigo).encode())
        escritor.write(json.dumps(cuerpo).encode())
        await escritor.drain()
    except Exception as e:
        print("HTTP error:", e)
    finally:
        escritor.close()
        await escritor.wait_closed()

def conectar_wifi():
    sta = network.WLAN(network.STA_IF)
    sta.active(True)
    if WIFI_SSID != "MI_RED":
        sta.connect(WIFI_SSID, WIFI_CLAVE)
        t0 = time.ticks_ms()
        while not sta.isconnected() and time.ticks_diff(time.ticks_ms(), t0) < 10000:
            time.sleep_ms(200)
    if sta.isconnected():
        return sta.ifconfig()[0]
    ap = network.WLAN(network.AP_IF)            # modo punto de acceso
    ap.active(True)
    ap.config(essid=AP_SSID, password=AP_CLAVE)
    return ap.ifconfig()[0]

async def principal():
    estado["ip"] = conectar_wifi()
    print("Estacion lista en http://%s/estado" % estado["ip"])
    balanza.tara()
    await asyncio.start_server(atender, "0.0.0.0", 80)
    await tarea_banda()

asyncio.run(principal())
```

</details>

<details>
<summary><b>Código: <code>3_carro_esp32/main.py</code></b> (carro)</summary>

```python
# main.py  -  ESP32-S3 "CARRO" (MicroPython)
# Carro recolector de vasos: aparcamiento por voz, seguidor de línea y esquive
# de obstáculos. Recibe órdenes por Wi-Fi (HTTP) desde la app de Streamlit,
# que convierte la voz en texto.
#
# Rutas HTTP:  /cmd?c=estacionar   /cmd?c=meta   /cmd?c=adelante ...   /estado
# Órdenes:     estacionar | meta | alto | adelante | atras | izquierda | derecha | base

import asyncio
import json
import time
import network
from machine import Pin, PWM, time_pulse_us

# ------------------------------------------------------------------ CONFIGURACION
WIFI_SSID = "MI_RED"
WIFI_CLAVE = "MI_CLAVE"
AP_SSID, AP_CLAVE = "Carro-Monedas", "12345678"

# TB6612FNG (A = motor izquierdo, B = motor derecho)
AIN1, AIN2, PWMA = 4, 5, 6
BIN1, BIN2, PWMB = 7, 15, 16
STBY = 17
# HC-SR04 (ECHO con divisor 1 kΩ / 2 kΩ: 5 V -> 3,3 V)
TRIG_FRONTAL, ECHO_FRONTAL = 1, 2
TRIG_TRASERO, ECHO_TRASERO = 41, 42
# Sensores de línea TCRT5000 (salida digital: 1 = negro / línea)
IR_IZQ, IR_CEN, IR_DER = 8, 9, 10
LINEA_ES = 1
PIN_BUZZER = 18

V_CRUCERO = 0.55          # fracción de PWM en la pista
V_GIRO = 0.45
DIST_PARQUEO_CM = 6.0     # se detiene a esta distancia de la estación
DIST_OBSTACULO_CM = 18.0
LADOS_ESQUIVE = ["der", "izq", "der"]    # por dónde rodear cada obstáculo de la pista
T_MANUAL_RECTO, T_MANUAL_GIRO = 1000, 450   # ms (calibrar en el piso real)
RAMPA = 0.08              # cambio máximo de PWM por ciclo de 20 ms (arranque suave)

# ------------------------------------------------------------------ HARDWARE
class Motor:
    def __init__(self, in1, in2, pwm, invertido=False):
        self.in1 = Pin(in1, Pin.OUT, value=0)
        self.in2 = Pin(in2, Pin.OUT, value=0)
        self.pwm = PWM(Pin(pwm), freq=1000, duty_u16=0)
        self.inv = invertido
        self.actual = 0.0

    def poner(self, v):
        v = max(-1.0, min(1.0, v))
        if self.inv:
            v = -v
        self.in1.value(1 if v > 0 else 0)
        self.in2.value(1 if v < 0 else 0)
        self.pwm.duty_u16(int(abs(v) * 65535))

motor_izq = Motor(AIN1, AIN2, PWMA)
motor_der = Motor(BIN1, BIN2, PWMB, invertido=True)   # montado en espejo
Pin(STBY, Pin.OUT, value=1)
trig_f, echo_f = Pin(TRIG_FRONTAL, Pin.OUT, value=0), Pin(ECHO_FRONTAL, Pin.IN)
trig_t, echo_t = Pin(TRIG_TRASERO, Pin.OUT, value=0), Pin(ECHO_TRASERO, Pin.IN)
ir = [Pin(IR_IZQ, Pin.IN), Pin(IR_CEN, Pin.IN), Pin(IR_DER, Pin.IN)]
buzzer = Pin(PIN_BUZZER, Pin.OUT, value=0)

def distancia_cm(trig, echo):
    trig.value(0)
    time.sleep_us(2)
    trig.value(1)
    time.sleep_us(10)
    trig.value(0)
    t = time_pulse_us(echo, 1, 15000)      # 15 ms = 2,5 m como máximo
    return 250.0 if t < 0 else t / 58.0

def linea():
    return [1 if s.value() == LINEA_ES else 0 for s in ir]

# ------------------------------------------------------------------ ESTADO
st = {"modo": "LIBRE", "mensaje": "Listo", "dist_frontal_cm": 0.0, "dist_trasera_cm": 0.0,
      "linea": [0, 0, 0], "vel": [0.0, 0.0], "esquivados": 0, "ip": ""}
objetivo = [0.0, 0.0]       # PWM deseado (izquierdo, derecho)
manual_hasta = 0
ultimo_giro = 1
pasos_esquive = []

def ordenar(texto):
    """Interpreta la orden que llega de la app (texto reconocido por voz)."""
    global manual_hasta, pasos_esquive
    t = texto.lower()
    ahora = time.ticks_ms()
    if "estacion" in t or "parque" in t or "aparca" in t:
        st["modo"], st["mensaje"] = "ESTACIONANDO", "Retrocediendo hacia la estacion"
    elif "meta" in t or "entrega" in t:
        st["modo"], st["mensaje"] = "LINEA", "Siguiendo la pista hacia la meta"
        st["esquivados"] = 0
    elif "alto" in t or "para" in t or "deten" in t:
        st["modo"], st["mensaje"] = "LIBRE", "Alto"
        pasos_esquive = []
    elif "adelante" in t or "avanza" in t:
        st["modo"], objetivo[0], objetivo[1] = "MANUAL", V_GIRO, V_GIRO
        manual_hasta = time.ticks_add(ahora, T_MANUAL_RECTO)
    elif "atras" in t or "retrocede" in t:
        st["modo"], objetivo[0], objetivo[1] = "MANUAL", -V_GIRO, -V_GIRO
        manual_hasta = time.ticks_add(ahora, T_MANUAL_RECTO)
    elif "izquierda" in t:
        st["modo"], objetivo[0], objetivo[1] = "MANUAL", -V_GIRO, V_GIRO
        manual_hasta = time.ticks_add(ahora, T_MANUAL_GIRO)
    elif "derecha" in t:
        st["modo"], objetivo[0], objetivo[1] = "MANUAL", V_GIRO, -V_GIRO
        manual_hasta = time.ticks_add(ahora, T_MANUAL_GIRO)
    else:
        return False
    return True

def plan_esquive(lado):
    """Secuencia (izq, der, ms) para rodear un obstáculo y volver a la línea."""
    s = 1 if lado == "der" else -1
    g = V_GIRO
    return [(g * s, -g * s, 420), (V_CRUCERO, V_CRUCERO, 900), (-g * s, g * s, 420),
            (V_CRUCERO, V_CRUCERO, 1000), (-g * s, g * s, 420), ("BUSCAR", s, 2500)]

async def control():
    """Bucle de control a 50 Hz."""
    global ultimo_giro, pasos_esquive
    t_paso = time.ticks_ms()
    t_pitido = 0
    while True:
        ahora = time.ticks_ms()
        modo = st["modo"]
        d_f = distancia_cm(trig_f, echo_f)
        d_t = distancia_cm(trig_t, echo_t) if modo in ("ESTACIONANDO", "LIBRE", "ESTACIONADO") else st["dist_trasera_cm"]
        l = linea()
        st["dist_frontal_cm"], st["dist_trasera_cm"], st["linea"] = round(d_f, 1), round(d_t, 1), l

        if modo == "MANUAL":
            if time.ticks_diff(ahora, manual_hasta) >= 0 or (objetivo[0] > 0 and objetivo[1] > 0 and d_f < DIST_OBSTACULO_CM):
                objetivo[0] = objetivo[1] = 0.0
                st["modo"] = "LIBRE"

        elif modo == "ESTACIONANDO":
            # Aparcamiento en reversa con el ultrasonido trasero (como un sensor de parqueo)
            if d_t <= DIST_PARQUEO_CM:
                objetivo[0] = objetivo[1] = 0.0
                st["modo"], st["mensaje"] = "ESTACIONADO", "Estacionado a %.1f cm" % d_t
                buzzer.value(1)
                await asyncio.sleep_ms(400)
                buzzer.value(0)
            else:
                v = -0.45 if d_t > 25 else -0.28
                corr = 0.0
                if l[0] and not l[2]:          # la guía quedó a la izquierda (en reversa se corrige al revés)
                    corr = 0.10
                elif l[2] and not l[0]:
                    corr = -0.10
                objetivo[0], objetivo[1] = v + corr, v - corr
                periodo = max(80, int(d_t * 20))       # pitidos más rápidos al acercarse
                if time.ticks_diff(ahora, t_pitido) > periodo:
                    t_pitido = ahora
                    buzzer.value(not buzzer.value())

        elif modo == "LINEA":
            if d_f < DIST_OBSTACULO_CM:                 # obstáculo: plan de esquive
                lado = LADOS_ESQUIVE[st["esquivados"] % len(LADOS_ESQUIVE)]
                pasos_esquive = plan_esquive(lado)
                t_paso = ahora
                st["modo"], st["mensaje"] = "ESQUIVANDO", "Esquivando obstaculo por la %s" % lado
            elif l == [1, 1, 1]:                        # franja de la meta
                objetivo[0] = objetivo[1] = 0.0
                st["modo"], st["mensaje"] = "EN_META", "Llego a la meta"
            elif l[1] and not l[0] and not l[2]:
                objetivo[0] = objetivo[1] = V_CRUCERO
            elif l[0]:
                objetivo[0], objetivo[1] = 0.1, V_CRUCERO
                ultimo_giro = -1
            elif l[2]:
                objetivo[0], objetivo[1] = V_CRUCERO, 0.1
                ultimo_giro = 1
            else:                                       # perdió la línea: girar hacia el último lado
                objetivo[0], objetivo[1] = (V_GIRO, -V_GIRO * 0.3) if ultimo_giro > 0 else (-V_GIRO * 0.3, V_GIRO)

        elif modo == "ESQUIVANDO":
            if not pasos_esquive:
                st["modo"] = "LINEA"
                st["esquivados"] += 1
            else:
                a, b, ms = pasos_esquive[0]
                if a == "BUSCAR":                       # avanzar hasta reencontrar la línea
                    objetivo[0] = objetivo[1] = V_CRUCERO * 0.7
                    if l[1] or time.ticks_diff(ahora, t_paso) > ms:
                        pasos_esquive.pop(0)
                        pasos_esquive.insert(0, (V_GIRO * b, -V_GIRO * b, 300))   # alinearse
                        t_paso = ahora
                else:
                    objetivo[0], objetivo[1] = a, b
                    if time.ticks_diff(ahora, t_paso) > ms:
                        pasos_esquive.pop(0)
                        t_paso = ahora
        else:
            objetivo[0] = objetivo[1] = 0.0
            buzzer.value(0)

        # Rampa: el PWM cambia poco a poco (movimiento suave, sin derrapes)
        for i, m in enumerate((motor_izq, motor_der)):
            d = objetivo[i] - m.actual
            m.actual += max(-RAMPA, min(RAMPA, d))
            m.poner(m.actual)
        st["vel"] = [round(motor_izq.actual, 2), round(motor_der.actual, 2)]
        await asyncio.sleep_ms(20)

# ------------------------------------------------------------------ SERVIDOR
def parsear(ruta):
    if "?" not in ruta:
        return ruta, {}
    camino, q = ruta.split("?", 1)
    args = {}
    for par in q.split("&"):
        if "=" in par:
            k, v = par.split("=", 1)
            args[k] = v.replace("+", " ").replace("%20", " ")
    return camino, args

def manejar(ruta):
    camino, args = parsear(ruta)
    if camino == "/estado":
        return "200 OK", st
    if camino == "/cmd":
        ok = ordenar(args.get("c", ""))
        return ("200 OK" if ok else "400 Bad Request"), {"ok": ok, "modo": st["modo"], "mensaje": st["mensaje"]}
    return "404 Not Found", {"rutas": ["/estado", "/cmd?c=orden"]}

async def atender(lector, escritor):
    try:
        linea_http = await lector.readline()
        partes = linea_http.decode().split(" ")
        ruta = partes[1] if len(partes) > 1 else "/"
        while True:
            h = await lector.readline()
            if not h or h == b"\r\n":
                break
        codigo, cuerpo = manejar(ruta)
        escritor.write(("HTTP/1.1 %s\r\nContent-Type: application/json\r\n"
                        "Access-Control-Allow-Origin: *\r\nConnection: close\r\n\r\n" % codigo).encode())
        escritor.write(json.dumps(cuerpo).encode())
        await escritor.drain()
    except Exception as e:
        print("HTTP error:", e)
    finally:
        escritor.close()
        await escritor.wait_closed()

def conectar_wifi():
    sta = network.WLAN(network.STA_IF)
    sta.active(True)
    if WIFI_SSID != "MI_RED":
        sta.connect(WIFI_SSID, WIFI_CLAVE)
        t0 = time.ticks_ms()
        while not sta.isconnected() and time.ticks_diff(time.ticks_ms(), t0) < 10000:
            time.sleep_ms(200)
    if sta.isconnected():
        return sta.ifconfig()[0]
    ap = network.WLAN(network.AP_IF)
    ap.active(True)
    ap.config(essid=AP_SSID, password=AP_CLAVE)
    return ap.ifconfig()[0]

async def principal():
    st["ip"] = conectar_wifi()
    print("Carro listo en http://%s/estado" % st["ip"])
    await asyncio.start_server(atender, "0.0.0.0", 80)
    await control()

asyncio.run(principal())
```

</details>

---

## 11. Aplicación Streamlit: dashboard y control por voz

- **Dashboard (actualización cada 1 s con `st.fragment`)**: valor procesado, cantidad, peso, rechazadas y estado de la estación; barras por denominación, torta de valor, línea de valor acumulado; tabla de vasos; estado y carga del carro; entregas en la meta.
- **Voz**: `streamlit-mic-recorder` convierte la voz a texto (español). `interpretar()` lo traduce a una orden aunque la frase sea natural (*«parquéate en la zona de carga»* → `estacionar`; *«carga el vaso de mil»* → `cargar 1000`). También hay botones y una caja de texto.
- **Dos orígenes de datos**: *Simulación* (lee `estado_sim.json` y envía las órdenes por UDP a PyBullet) o *Sistema real* (HTTP a las dos ESP32-S3 por Wi-Fi).

<details>
<summary><b>Código: <code>4_app_streamlit/app.py</code></b></summary>

```python
"""
app.py  -  Dashboard en tiempo real + control del carro por voz (Streamlit)

Funciona con dos orígenes de datos:
  * Simulación (PyBullet): lee 5_simulacion/estado_sim.json y envía las órdenes
    al simulador por UDP (127.0.0.1:5005).
  * Sistema real (ESP32-S3): lee /estado de la estación y del carro por Wi-Fi
    (HTTP) y envía las órdenes al carro (/cmd) y a la estación (/entregar).

Ejecutar:  streamlit run app.py
"""

import json
import os
import re
import socket
import time
import unicodedata
import urllib.parse

import pandas as pd
import plotly.express as px
import requests
import streamlit as st

try:
    from streamlit_mic_recorder import speech_to_text
except ImportError:          # la app funciona igual con botones y texto
    speech_to_text = None

AQUI = os.path.dirname(os.path.abspath(__file__))
ARCHIVO_SIM = os.path.join(AQUI, "..", "5_simulacion", "estado_sim.json")
DENOMINACIONES = [50, 100, 200, 500, 1000]
PESOS = {50: 2.00, 100: 3.34, 200: 4.61, 500: 7.14, 1000: 9.95}

st.set_page_config(page_title="Logística de Monedas Inteligentes", page_icon="🪙", layout="wide")

# ------------------------------------------------------------------ BARRA LATERAL
st.sidebar.title("⚙️ Conexión")
origen = st.sidebar.radio("Origen de datos", ["Simulación (PyBullet)", "Sistema real (ESP32-S3)"])
SIM = origen.startswith("Simulación")
ip_estacion = st.sidebar.text_input("IP de la estación", "192.168.1.50", disabled=SIM)
ip_carro = st.sidebar.text_input("IP del carro", "192.168.1.51", disabled=SIM)
intervalo = st.sidebar.slider("Actualizar cada (s)", 0.5, 5.0, 1.0, 0.5)
st.sidebar.caption("En modo real, el PC y las dos ESP32-S3 deben estar en la misma red Wi-Fi.")

if "historial" not in st.session_state:
    st.session_state.historial = []
if "registro" not in st.session_state:
    st.session_state.registro = []

# ------------------------------------------------------------------ DATOS
def leer_estado():
    """Estado normalizado del sistema (simulado o real)."""
    if SIM:
        try:
            with open(ARCHIVO_SIM, encoding="utf-8") as f:
                e = json.load(f)
        except (OSError, json.JSONDecodeError):
            return None, "Inicia la simulación: python simulacion_sistema.py"
        return {
            "conteo": {int(k): v for k, v in e["conteo"].items()},
            "valor_total": e["valor_total"], "peso_total_g": e["peso_total_g"],
            "monedas_total": e["monedas_total"], "rechazadas": e["rechazadas"],
            "estacion": e["estacion"], "ultima": e.get("ultima_moneda"),
            "vasos": e["vasos"], "carro": e["carro"], "entregas": e.get("entregas", []),
            "peso_medido_g": None,
        }, None
    try:
        est = requests.get("http://%s/estado" % ip_estacion, timeout=1.5).json()
    except Exception as ex:
        return None, "No responde la estación (%s): %s" % (ip_estacion, ex)
    try:
        car = requests.get("http://%s/estado" % ip_carro, timeout=1.5).json()
    except Exception:
        car = {"modo": "SIN CONEXION", "mensaje": "", "dist_frontal_cm": None, "dist_trasera_cm": None}
    vasos = [{"etiqueta": (int(k) if k.isdigit() else k), **v} for k, v in est["vasos"].items()]
    return {
        "conteo": {int(k): v for k, v in est["conteo"].items()},
        "valor_total": est["valor_total"], "peso_total_g": est["peso_total_g"],
        "monedas_total": est["monedas_total"], "rechazadas": est["rechazadas"],
        "estacion": est["estado"], "ultima": est.get("ultima"), "vasos": vasos,
        "carro": car, "entregas": [], "peso_medido_g": est.get("peso_medido_g"),
    }, None

def sin_tildes(texto):
    return "".join(c for c in unicodedata.normalize("NFD", texto.lower()) if unicodedata.category(c) != "Mn")

def interpretar(texto):
    """Convierte la frase dicha en una orden del sistema."""
    t = sin_tildes(texto)
    if any(p in t for p in ("estaciona", "parquea", "aparca", "zona de carga")):
        return "estacionar"
    if "carga" in t or "subir el vaso" in t:
        numeros = re.findall(r"\d+", t.replace(".", ""))
        palabras = re.findall(r"[a-z]+", t)
        nombres = {50: "cincuenta", 100: "cien", 200: "doscientos", 500: "quinientos", 1000: "mil"}
        for d in sorted(DENOMINACIONES, reverse=True):
            if str(d) in numeros or nombres[d] in palabras:
                return "cargar %d" % d
        return "cargar"
    if "meta" in t or "entrega" in t:
        return "meta"
    if any(p in t for p in ("alto", "para", "detente", "frena")):
        return "alto"
    if "base" in t or "casa" in t or "garaje" in t:
        return "base"
    if "adelante" in t or "avanza" in t:
        return "adelante"
    if "atras" in t or "retrocede" in t or "reversa" in t:
        return "atras"
    if "izquierda" in t:
        return "izquierda"
    if "derecha" in t:
        return "derecha"
    return None

def enviar(orden):
    """Envía la orden al simulador (UDP) o a las ESP32-S3 (HTTP)."""
    if SIM:
        s = socket.socket(socket.AF_INET, socket.SOCK_DGRAM)
        s.sendto(orden.encode("utf-8"), ("127.0.0.1", 5005))
        s.close()
        return "Enviado al simulador"
    try:
        if orden.startswith("cargar"):
            partes = orden.split()
            url = "http://%s/entregar" % ip_estacion + (("?valor=" + partes[1]) if len(partes) > 1 else "")
        else:
            url = "http://%s/cmd?c=%s" % (ip_carro, urllib.parse.quote(orden))
        return requests.get(url, timeout=2).text
    except Exception as ex:
        return "Error: %s" % ex

def registrar(origen_txt, texto, orden, respuesta):
    st.session_state.registro.insert(0, {"hora": time.strftime("%H:%M:%S"), "origen": origen_txt,
                                         "dicho": texto, "orden": orden or "—", "respuesta": str(respuesta)[:80]})

# ------------------------------------------------------------------ INTERFAZ
st.title("🪙 Sistema de Logística de Monedas Inteligentes")
st.caption("Grupo 5 · Selector en cadena de vasos por visión computacional · Carro con ESP32-S3 y aparcamiento por voz")
tab_dash, tab_voz = st.tabs(["📊 Dashboard en tiempo real", "🎙️ Carro por voz"])

with tab_dash:
    @st.fragment(run_every=intervalo)
    def panel():
        e, error = leer_estado()
        if error:
            st.warning(error)
            return
        h = st.session_state.historial
        h.append({"t": time.strftime("%H:%M:%S"), "valor": e["valor_total"], "monedas": e["monedas_total"]})
        del h[:-120]

        c1, c2, c3, c4, c5 = st.columns(5)
        c1.metric("💰 Valor procesado", "$%s" % format(e["valor_total"], ",").replace(",", "."))
        c2.metric("🪙 Monedas", e["monedas_total"])
        c3.metric("⚖️ Peso", "%.2f g" % e["peso_total_g"])
        c4.metric("🚫 Rechazadas", e["rechazadas"])
        c5.metric("🏭 Estación", e["estacion"])

        df = pd.DataFrame({"Denominación": ["$%d" % d for d in DENOMINACIONES],
                           "Cantidad": [e["conteo"].get(d, 0) for d in DENOMINACIONES],
                           "Valor": [d * e["conteo"].get(d, 0) for d in DENOMINACIONES],
                           "Peso (g)": [round(PESOS[d] * e["conteo"].get(d, 0), 2) for d in DENOMINACIONES]})
        g1, g2, g3 = st.columns(3)
        g1.plotly_chart(px.bar(df, x="Denominación", y="Cantidad", text="Cantidad", color="Denominación",
                               title="Monedas por denominación"), use_container_width=True)
        g2.plotly_chart(px.pie(df, names="Denominación", values="Valor", title="Valor por denominación",
                               hole=0.45), use_container_width=True)
        g3.plotly_chart(px.line(pd.DataFrame(h), x="t", y="valor", markers=True,
                                title="Valor acumulado en el tiempo"), use_container_width=True)

        izq, der = st.columns([3, 2])
        with izq:
            st.subheader("🥤 Cadena de vasos")
            vasos = pd.DataFrame(e["vasos"])
            if not vasos.empty:
                vasos["etiqueta"] = vasos["etiqueta"].apply(lambda v: "$%d" % v if isinstance(v, int) else str(v))
                st.dataframe(vasos.rename(columns={"etiqueta": "Vaso", "monedas": "Monedas", "valor": "Valor ($)",
                                                   "peso": "Peso (g)"}), hide_index=True, use_container_width=True)
            if e["ultima"]:
                st.info("Última moneda: %s" % json.dumps(e["ultima"], ensure_ascii=False))
            if e.get("peso_medido_g") is not None:
                st.caption("Peso medido por la celda de carga en la entrega: %.2f g" % e["peso_medido_g"])
        with der:
            st.subheader("🚗 Carro")
            car = e["carro"]
            a, b = st.columns(2)
            a.metric("Modo", car.get("modo", "—"))
            b.metric("Sensor trasero", "%s cm" % car.get("dist_trasera_cm"))
            st.write(car.get("mensaje", ""))
            if car.get("carga"):
                st.success("Carga: vaso de $%s con %d monedas ($%d)" % (
                    car["carga"]["etiqueta"], car["carga"]["monedas"], car["carga"]["valor"]))
            if e["entregas"]:
                st.write("Entregas en la meta:")
                st.dataframe(pd.DataFrame(e["entregas"]), hide_index=True, use_container_width=True)

    panel()

with tab_voz:
    st.subheader("🎙️ Aparcamiento y control por voz")
    st.write("Di por ejemplo: **«estaciona el carro»**, **«carga el vaso de quinientos»**, "
             "**«ve a la meta»**, **«alto»**, **«gira a la izquierda»**.")
    if speech_to_text is not None:
        texto = speech_to_text(language="es", start_prompt="🎤 Hablar", stop_prompt="⏹️ Enviar",
                               just_once=True, use_container_width=True, key="voz")
        if texto:
            orden = interpretar(texto)
            respuesta = enviar(orden) if orden else "No entendí la orden"
            registrar("voz", texto, orden, respuesta)
            (st.success if orden else st.error)("🗣️ «%s» → %s" % (texto, orden or "sin orden"))
    else:
        st.warning("Instala streamlit-mic-recorder para usar el micrófono (pip install streamlit-mic-recorder).")

    escrito = st.text_input("…o escribe la orden", placeholder="estaciona el carro")
    if st.button("Enviar texto") and escrito:
        orden = interpretar(escrito)
        registrar("texto", escrito, orden, enviar(orden) if orden else "No entendí la orden")

    st.write("Botones rápidos:")
    cols = st.columns(8)
    for col, orden in zip(cols, ["estacionar", "cargar", "meta", "alto", "adelante", "atras", "izquierda", "derecha"]):
        if col.button(orden.capitalize(), use_container_width=True):
            registrar("botón", orden, orden, enviar(orden))

    if st.session_state.registro:
        st.dataframe(pd.DataFrame(st.session_state.registro[:15]), hide_index=True, use_container_width=True)
```

</details>

---

## 12. Simulación en PyBullet

La simulación representa el apartado actual por estar implementado en un entorno virtual mediante PyBullet.

### 12.1 Diagrama general de la simulación

```mermaid
flowchart TD
    A[Tolva de alimentación] --> B[Monedas / caída]
    B --> C[Banda transportadora]
    C --> D[Sensor de identificación]
    D --> E[Selector]
    E --> F[Toboganes]
    F --> G[Vasos]
    G --> H[Contadores]
    H --> I[Carro autónomo]
    I --> J[Zona de entrega]
    J --> K[Meta]
```

### 12.2 Componentes virtuales

La simulación representa:

- **Tolva de alimentación:** almacena las monedas antes de iniciar el proceso.
- **Banda transportadora:** desplaza las monedas hacia el punto de identificación.
- **Sensor de identificación:** determina la denominación de la moneda cuando llega al punto de clasificación.
- **Selector:** incorpora el mecanismo encargado de dirigir la moneda.
- **Toboganes:** cada recorrido corresponde a una denominación.
- **Vasos:** recibe las monedas clasificadas.
- **Contador:** registra la cantidad total de monedas procesadas y su valor acumulado.
- **Carro autónomo:** transporta los vasos hacia la zona de entrega.
- **Obstáculos:** representan los elementos que el carro debe evitar.
- **Zona de entrega:** punto donde el carro recoge los vasos.
- **Meta principal:** final del recorrido.

### 12.3 Denominaciones utilizadas

La simulación trabaja con las siguientes denominaciones:

| Denominación | Vaso asignado |
|:---:|:---:|
| $50 | Vaso 1 |
| $100 | Vaso 2 |
| $200 | Vaso 3 |
| $500 | Vaso 4 |
| $1.000 | Vaso 5 |

Las denominaciones se encuentran definidas directamente en el programa de simulación.

### 12.4 Flujo de funcionamiento

La simulación realiza el siguiente flujo de funcionamiento:

1. Las monedas se generan dentro de la tolva.
2. Las monedas descienden hacia la zona de caída.
3. Cada moneda entra a la banda transportadora.
4. La banda desplaza la moneda hasta el sensor.
5. Cuando la moneda llega al sensor se identifica su denominación.
6. El sistema determina el canal correspondiente.
7. La moneda sigue la trayectoria del tobogán.
8. La moneda llega al vaso correspondiente.
9. Se actualiza la cantidad de monedas y el valor total.
10. Cuando todas las monedas han sido clasificadas, se activa el carro autónomo.
11. El carro realiza una trayectoria definida para recolectarlas.
12. El carro recoge los vasos.
13. Los transporta hacia la zona de entrega.
14. Finalmente se desplaza hasta la meta.

### 12.5 Archivos de la simulación

La simulación se encuentra organizada de la siguiente manera:

```text
5_simulacion/
│
├── sistema_monedas_osbtaculos_distribuidos.py
│   └── Código principal de la simulación
│
├── selector_monedas.py; contador_carro.py
│   └── Dependencias necesarias para ejecutar la simulación
│
└── SIMULACIÓN.mp4
    └── Evidencia generada por la simulación
```

El archivo principal tiene como objetivo representar el funcionamiento completo de la simulación, incluyendo la clasificación de monedas, el transporte de los vasos y el recorrido del carro autónomo.

### 12.6 Tecnologías utilizadas

La simulación utiliza:

- **Python 3**
- **PyBullet**

## 13. Paso a paso para ejecutar

### 13.1 Instalación (PC)

```powershell
git clone <URL de este repositorio>
cd <carpeta del repositorio>
python -m pip install -r requisitos.txt
```

### 13.2 Simulación + dashboard + voz (sin hardware)

Terminal 1 (simulación):

```powershell
cd 5_simulacion
python simulacion_sistema.py            # interactiva (teclas y voz)
python simulacion_sistema.py --demo     # todo automático
```

Terminal 2 (app):

```powershell
cd 4_app_streamlit
streamlit run app.py
```

En la app, deja **Origen = Simulación**, abre la pestaña **🎙️ Carro por voz** y di *«estaciona el carro»*, *«carga el vaso de quinientos»* y *«ve a la meta»*.

### 13.3 CAD

```powershell
cd 6_cad
python generar_cad.py        # regenera carro.scad, carro_ensamble.stl, carro.urdf y plano_carro.png
```

Abre `carro.scad` en OpenSCAD. Cambia `pieza = "chasis";` (o `piso2`, `portavaso`, `soporte_sensor`) y exporta cada parte a STL con F6 → F7.

### 13.4 Sistema real

1. **Firmware MicroPython** en cada ESP32-S3 (ESP32_GENERIC_S3):
   ```powershell
   python -m esptool --chip esp32s3 --port COM7 erase_flash
   python -m esptool --chip esp32s3 --port COM7 --baud 460800 write_flash -z 0x0 ESP32_GENERIC_S3-xxxx.bin
   ```
2. **Configurar el Wi-Fi.** En cada `main.py`, cambia `WIFI_SSID` y `WIFI_CLAVE` (si los dejas así, la placa crea la red `Estacion-Monedas` o `Carro-Monedas`, clave `12345678`).
3. **Cargar los programas:**
   ```powershell
   python -m mpremote connect COM7 fs cp .\2_estacion_esp32\main.py :main.py
   python -m mpremote connect COM7 reset
   python -m mpremote connect COM8 fs cp .\3_carro_esp32\main.py :main.py
   python -m mpremote connect COM8 reset
   ```
4. **Ver la IP de cada placa:** `python -m mpremote connect COM7 repl` muestra `Estacion lista en http://192.168.x.x/estado` (salir con Ctrl + ]).
5. **Calibrar y arrancar la visión:**
   ```powershell
   cd 1_vision
   python vision_monedas.py --calibrar 1000      # pon una moneda de $1000 y presiona c
   python vision_monedas.py --ip 192.168.x.x     # IP de la estación
   ```
6. **App:** `streamlit run 4_app_streamlit/app.py` → Origen = **Sistema real**, escribe las dos IP.

---

## 14. Resultados de las pruebas

| Prueba | Resultado |
|---|---|
| Visión sobre las 5 monedas renderizadas en la cámara de inspección | **5/5 correctas**; error de diámetro ≤ 0,05 mm (17,0 · 20,35 · 22,41 · 23,7 · 26,71 mm) |
| Demo completa en simulación (10 monedas aleatorias) | **10/10 clasificadas y depositadas** en su vaso; $3200 y 47,6 g en el dashboard |
| Aparcamiento por orden de voz (UDP desde la app) | Estacionado a **1,5 cm reales** del borde de la estación |
| Carga y recorrido a la meta | Vaso transferido al carro; **3 obstáculos esquivados**; "ENTREGADO en la meta" |
| Firmware de la estación (MicroPython con sensores simulados) | `/moneda` → clasifica y suma; *timeout* → rechazo; `/entregar` → vacía el vaso |
| Firmware del carro (MicroPython con sensores simulados) | Estaciona al llegar a 5,2 cm; sigue la línea; esquiva; se detiene en la franja de meta |
| Interpretación de frases | *«Cargá el de 1000»* → `cargar 1000`; *«parquéate en la zona de carga»* → `estacionar` |

> Las pruebas de firmware se hicieron en MicroPython (puerto Unix) con módulos `machine` y `network` simulados. Las pruebas en el hardware real están en la sección siguiente.

---

## 15. Qué hace falta (trabajo pendiente)

### Para completar el grupo 5

- [ ] **Construir la estación física:** banda con rodillos impresos, compuerta y estructura de la cámara con anillo LED (la luz uniforme es clave para medir el color).
- [ ] **Mecanismo de la cadena de vasos:** elegir entre correa GT2 o cadena de rodillos, imprimir los soportes de vaso y ajustar `PASOS_POR_PUESTO` con el piñón real.
- [ ] **Calibrar la visión con monedas reales:** px/mm, `UMBRAL_BRILLO` y `UMBRAL_SATURACION`; hacer una **matriz de confusión** con al menos 50 monedas por denominación.
- [ ] **Calibrar la celda de carga** (`ESCALA_HX711`) con pesos conocidos y comparar el peso medido con el calculado.
- [ ] **Imprimir y montar el carro** del CAD; medir y ajustar `T_MANUAL_*`, `V_CRUCERO` y la rampa en el piso real.
- [ ] **Pista física** con línea negra de 20 mm, franja de meta y los 3 obstáculos; ajustar `LADOS_ESQUIVE` según su posición.
- [ ] **Coordinación automática estación ↔ carro** (por ejemplo, con ESP-NOW): que el empujador actúe solo cuando el carro confirme `ESTACIONADO`, sin pasar por la app.
- [ ] **Encoders en las ruedas** para que los giros por voz sean en grados y no por tiempo.
- [ ] **Video de evidencia** del sistema real y de la simulación.

### Del sistema general (otros módulos de la arquitectura)

- [ ] **Brazo "tapa vaso"** del módulo de transporte y embalaje.
- [ ] **Chatbot por voz** que comente el proyecto con los datos del dashboard (el curso ya tiene la base en `9) Chatbot_Voz_Streamlit`).
- [ ] **Persistencia** del historial (CSV o base de datos) para el dashboard.
- [ ] **Integración con los demás grupos** (por ejemplo, el dron de envío de monedas del grupo 6).

---

## 16. Estructura del repositorio

```text
├── 1_vision/
│   ├── vision_monedas.py          ← identificación de monedas (OpenCV)
│   └── requirements.txt
├── 2_estacion_esp32/
│   └── main.py                    ← ESP32-S3 #1: banda, cadena de vasos, empujador, HX711, HTTP
├── 3_carro_esp32/
│   └── main.py                    ← ESP32-S3 #2: aparcamiento, seguidor de línea, esquive, HTTP
├── 4_app_streamlit/
│   ├── app.py                     ← dashboard en tiempo real + control por voz
│   └── requirements.txt
├── 5_simulacion/
│   ├── simulacion_sistema.py      ← simulación completa en PyBullet
│   └── requirements.txt
├── 6_cad/
│   ├── generar_cad.py             ← fuente de cotas → SCAD, STL, URDF y plano
│   ├── carro.scad                 ← CAD paramétrico (OpenSCAD)
│   ├── carro_ensamble.stl         ← ensamble 3D (mm)
│   ├── carro.urdf                 ← modelo para PyBullet
│   ├── plano_carro.png
│   └── render_carro_*.png
├── evidencias/                    ← capturas de la simulación (y videos)
├── requisitos.txt
└── README.md
```

### Referencias

- Repositorio base del curso: [dialejobv/U_Militar](https://github.com/dialejobv/U_Militar)
- Características de las monedas: [Banco de la República — normatividad de monedas](https://www.banrep.gov.co/es/normatividad/caracteristicas-monedas-billetes-monedas-conmemorativas)
- [PyBullet](https://pybullet.org) · [OpenCV](https://opencv.org) · [Streamlit](https://streamlit.io) · [MicroPython ESP32-S3](https://micropython.org/download/ESP32_GENERIC_S3/)

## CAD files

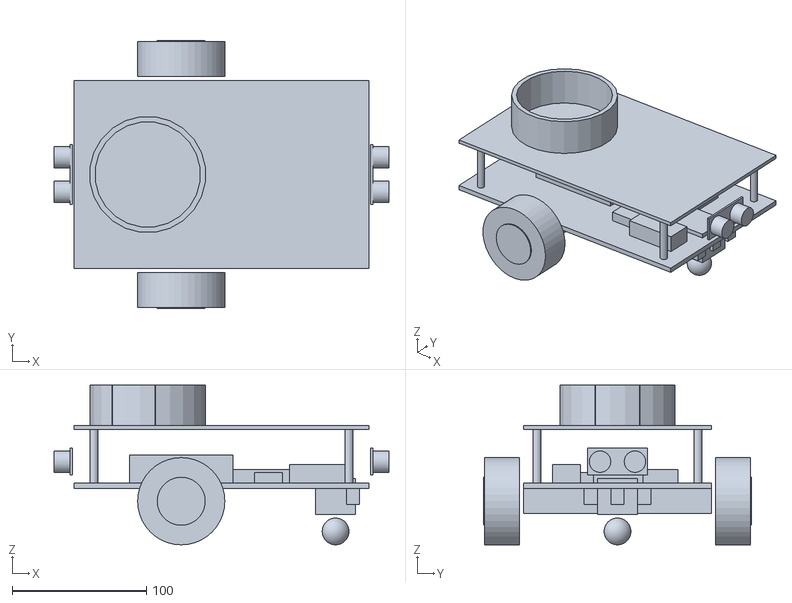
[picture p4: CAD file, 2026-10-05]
carro_ensamble.stl
249.6 x 200.0 x 119.0

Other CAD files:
carro.scad

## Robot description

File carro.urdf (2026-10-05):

<?xml version="1.0"?>
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
<robot name="carro_recolector">
  <link name="chasis">
    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
    <inertial><origin xyz="-0.06000 0 0"/><mass value="3.600"/>
      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</inertial>
  </link>

  <link name="rueda_izq">
    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
    <inertial><mass value="0.200"/>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</inertial>
  </link>
  <joint name="motor_izq" type="continuous">
    <parent link="chasis"/><child link="rueda_izq"/>
    <origin xyz="-0.12000 0.34400 -0.04600"/><axis xyz="0 1 0"/>
  </joint>

  <link name="rueda_der">
    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
    <inertial><mass value="0.200"/>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</inertial>
  </link>
  <joint name="motor_der" type="continuous">
    <parent link="chasis"/><child link="rueda_der"/>
    <origin xyz="-0.12000 -0.34400 -0.04600"/><axis xyz="0 1 0"/>
  </joint>
  <link name="rueda_loca">
    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
    <inertial><mass value="0.040"/>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</inertial>
  </link>
  <joint name="loca" type="fixed">
    <parent link="chasis"/><child link="rueda_loca"/>
    <origin xyz="0.34000 0.00000 -0.13600"/>
  </joint>
  <link name="porta_vaso"><inertial><mass value="0.001"/>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</inertial></link>
  <joint name="porta_vaso" type="fixed">
    <parent link="chasis"/><child link="porta_vaso"/>
    <origin xyz="-0.22000 0.00000 0.18000"/>
  </joint>
  <link name="sensor_frontal"><inertial><mass value="0.001"/>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</inertial></link>
  <joint name="sensor_frontal" type="fixed">
    <parent link="chasis"/><child link="sensor_frontal"/>
    <origin xyz="0.49600 0.00000 0.07200"/>
  </joint>
  <link name="sensor_trasero"><inertial><mass value="0.001"/>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</inertial></link>
  <joint name="sensor_trasero" type="fixed">
    <parent link="chasis"/><child link="sensor_trasero"/>
    <origin xyz="-0.49600 0.00000 0.07200" rpy="0 0 3.14159"/>
  </joint>
</robot>

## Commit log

2026-10-05 Update print statement from 'Hello' to 'Goodbye'
2026-10-05 Add car counter simulation with sensors and coins
